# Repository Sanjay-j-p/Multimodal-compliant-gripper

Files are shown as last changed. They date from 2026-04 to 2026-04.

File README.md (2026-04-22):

# Multimodal Compliant Gripper with Force Feedback

> 🏆 **1st Place — Ford ATP Industrial Grasping Challenge** | Overall Honorable Mention  
> StarkHacks 2026 · Purdue University · 750+ Participants · Prize: Bambu Lab P2S



[]()

---

## Overview

A self-adaptive robotic grasper that combines **passive mechanical compliance**, **computer vision**, and **real-time Hall effect force feedback** to reliably grasp a wide variety of industrial objects without manual reconfiguration.

Built in 36 hours at StarkHacks 2026, tested on Ford automotive parts including spark plugs, lug nuts, piston rods, sheet metal, and more. Demonstrated on a Universal Robots UR10e cobot.

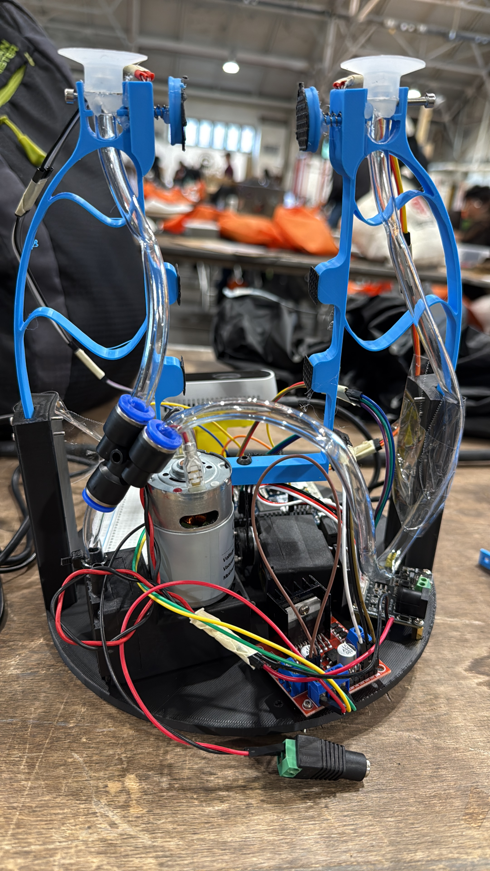
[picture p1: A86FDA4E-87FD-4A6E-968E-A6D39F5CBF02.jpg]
Gripper Hardware


---

## How It Works

### Grasp Decision Pipeline

```
RealSense D435i → SAM3 Segmentation → Depth Fusion → Grasp Classification → MQTT Command → Arduino Q → Actuator
```

1. **Capture** — Intel RealSense D435i streams aligned RGB + depth at 640×480 30fps
2. **Segment** — SAM3 via Roboflow API generates polygon masks for target objects
3. **Depth Fuse** — Mask projected onto depth matrix, point cloud extracted
4. **Classify** — Depth gap > 7 or std > 30 → `FINGER_GRASP`, else → `VACUUM`
5. **Execute** — MQTT command sent to Arduino Q, servo or pump actuated, Hall sensor monitors force

### Grasp Modes

| Mode | Trigger | Actuator |
|---|---|---|
| `FINGER_GRASP` | Hollow objects, irregular surfaces | SC Servo → compliant jaw |
| `VACUUM` | Large flat surfaces | DC pump → suction cups |

---

## System Architecture

### Three-Layer Control

```
[ Remote Client ]  ←→  MQTT  ←→  [ Linux Python Bridge ]  ←→  ArduinoBridge  ←→  [ Arduino Q ]
  mqtt_client.py                   mqtt_server_starkhacks.py                      mcu_starkhacks.ino
  - Send commands                  - Route MQTT to MCU                            - Servo control
  - Read force data                - Publish sensor data @ 20Hz                   - Pump PWM
                                   - Threading for async ops                      - Hall sensor read
```

### Force Feedback

Hall effect sensor reads displacement of a spring-loaded magnet in the fingertip. Displacement maps to contact force via:

```
F = -0.016 × M + 11.4   (calibrated linear regression, F in Newtons)
```

Where `M` is the raw analog Hall sensor reading. Published over MQTT at 20Hz for real-time monitoring.

---

## Hardware

| Component | Role |
|---|---|
| Compliant PLA fingers | Passive shape adaptation via flexure geometry |
| SC Servo (ID 1) | Jaw open/close, position range 1000–2200 |
| DC Vacuum Pump | Suction cup actuation, PWM controlled (0–255) |
| Suction Cups (×2) | Flat surface grasping |
| Hall Effect Sensor | Contact force estimation |
| Spring + Magnet | Displacement-to-force transduction |
| Arduino Q | MCU: all sensor reads + actuator control |
| Intel RealSense D435i | RGB-D perception, mounted on gripper |
| Linux laptop | MQTT broker + Python bridge server |
| UR10e | Robot arm (ISO 9409-1-50-4-M6 mount) |

More about the gripper: https://docs.google.com/document/d/11ORRFTWQD4MEVH4lIci75AOcohlwfsoFN2d4iKilZCc/edit?usp=sharing 

---

## Repository Structure

```
├── src/
│   ├── mcu_starkhacks.ino          # Arduino Q firmware
│   ├── mqtt_server_starkhacks.py   # Linux bridge server
│   ├── mqtt_client.py              # Remote command client
│   └── computer_vision.py          # Vision pipeline + grasp analysis
├── cad/
│   └── *.SLDPRT / *.STL            # SolidWorks CAD + print-ready files
└── README.md
```

---

## Software Setup

### Requirements

```bash
pip install paho-mqtt pyrealsense2 open3d opencv-python inference-sdk numpy
```

### Run

**1. Flash Arduino Q** with `src/mcu_starkhacks.ino`

**2. Start Linux bridge** (on robot laptop):
```bash
python src/mqtt_server_starkhacks.py
```

**3. Start vision pipeline** (point RealSense at scene, press `C` to capture):
```bash
python src/computer_vision.py
```

**4. Start remote client** (any machine on same network):
```bash
python src/mqtt_client.py
```

### Client Commands

| Key | Action |
|-----|---|
| `i` | Increase grip |
| `d` | Decrease grip |
| `r` | Release / reset |
| `p` | Pump ON |
| `o` | Pump OFF |
| `q` | Quit |

---

## Printing the Gripper

CAD files are in `/cad/`. Print settings:

- **Material**: PLA
- **Infill**: 20–30% for compliant fingers, 60%+ for structural mounts
- **Layer height**: 0.2mm
- **Supports**: Required for finger flexure zones
- **Printer**: Any FDM — tested on Bambu Lab P2S

---

## Team

| Name | Contribution |
|---|---|
| Sanjay Jayalakshmi Prabakar | Arduino Q MCU and Linux, Hall effect force feedback, vacuum/servo control |
| Sukesh J. Ranganathan | Mechanical design, CAD, 3D printing, assembly |
| Sai Siddartha Alleni | Vision pipeline, MQTT architecture |
| Yalamanchili Varshitha | Vision pipeline, Roboflow/SAM3 integration |

---

## Results

Tested on Ford automotive parts: spark plug, lug nut, piston rod, sheet metal, cabin air filter, door handle, wire harness, and more.

**[Watch full demo →](https://youtu.be/v_XWHwukWWc)**

---

## Built With

`Arduino Q` `Python` `MQTT` `SAM3` `Roboflow` `Intel RealSense` `PyRealSense2` `Open3D` `OpenCV` `SolidWorks` `SC Servo` `Universal Robots UR10e`

---

*StarkHacks 2026 · Humanoid Robotics Club · Purdue University · April 17–19, 2026*

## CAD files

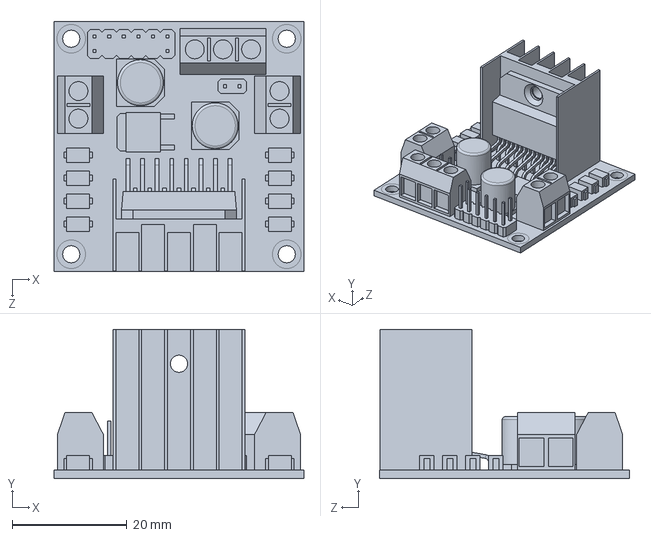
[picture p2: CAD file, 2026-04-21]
StarkHacks_CAD/L298N Motor Driver.SLDPRT
43.5 x 26.0 x 43.5 mm

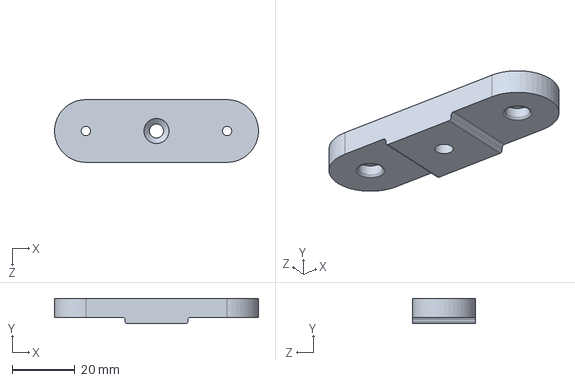
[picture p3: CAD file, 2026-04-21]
StarkHacks_CAD/Intel D435 mount.SLDPRT
65.0 x 8.00 x 20.0 mm

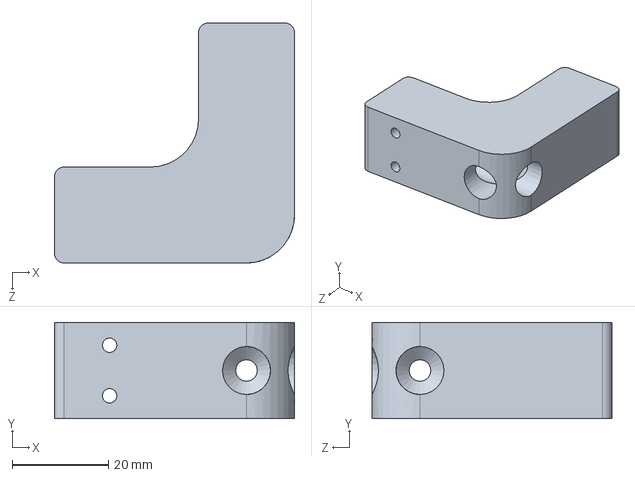
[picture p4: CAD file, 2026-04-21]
StarkHacks_CAD/Angle adapter 90 degree.SLDPRT
50.0 x 20.0 x 50.0 mm

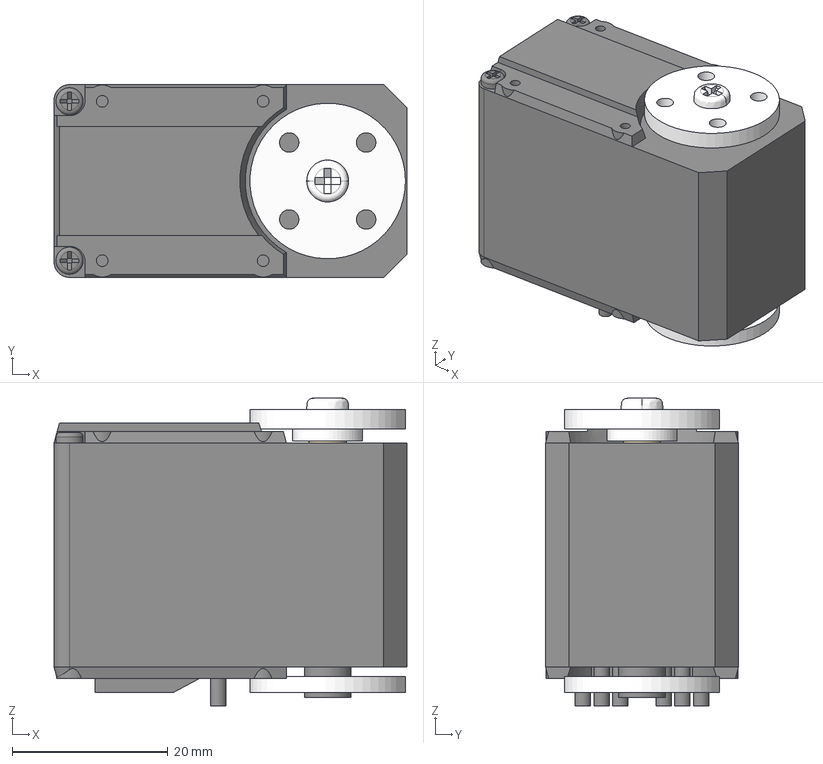
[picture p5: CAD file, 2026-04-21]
StarkHacks_CAD/STS3215_03a v1.step
45.4 x 24.8 x 39.6 mm
ac2
ac1
main

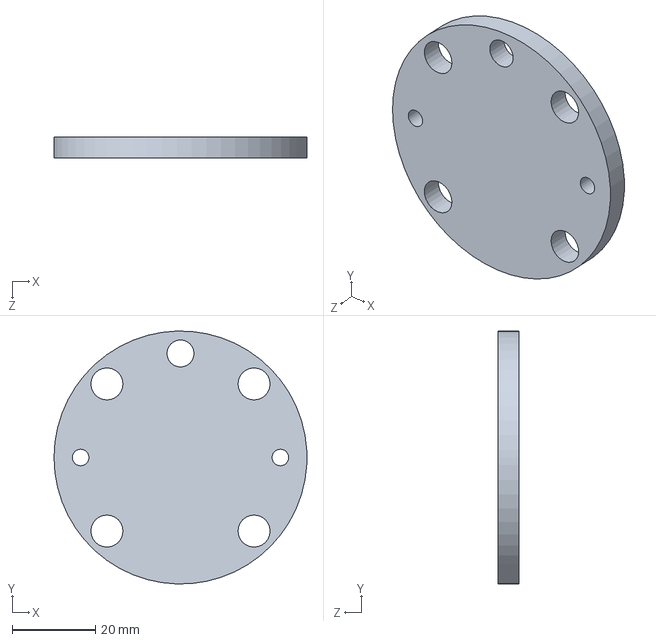
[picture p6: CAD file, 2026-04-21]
StarkHacks_CAD/Part for ur10e.SLDPRT
60.8 x 60.8 x 5.00 mm

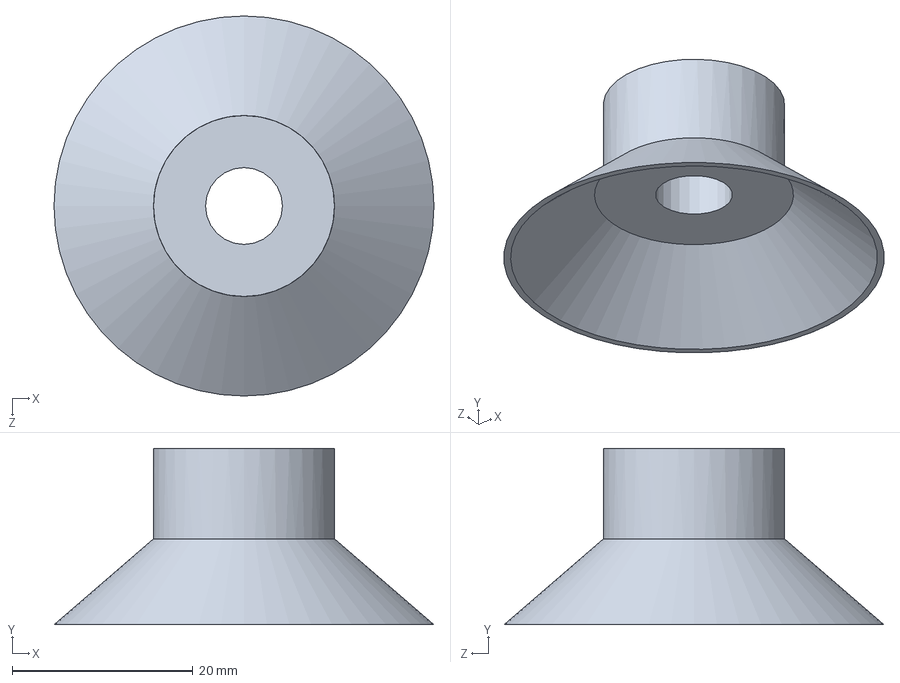
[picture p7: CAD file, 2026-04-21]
StarkHacks_CAD/VDF40XX.SLDPRT
42.0 x 19.5 x 42.0 mm

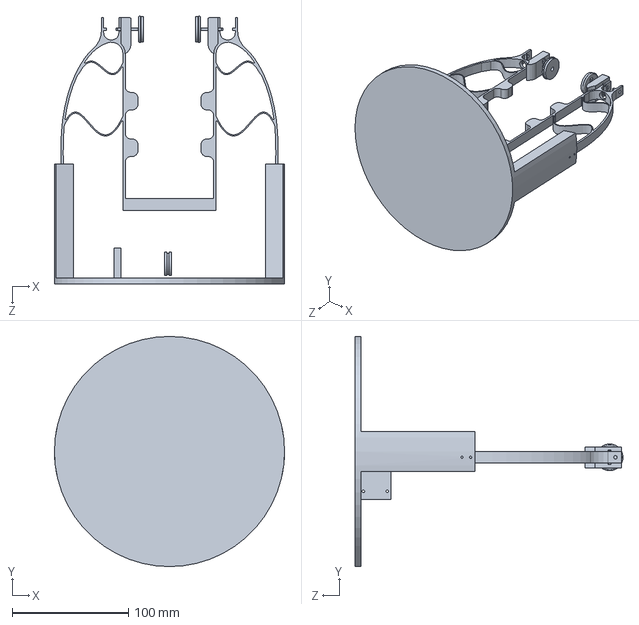
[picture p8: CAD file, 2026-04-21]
StarkHacks_CAD/Grasper Final.SLDPRT
197.7 x 197.7 x 230.1 mm

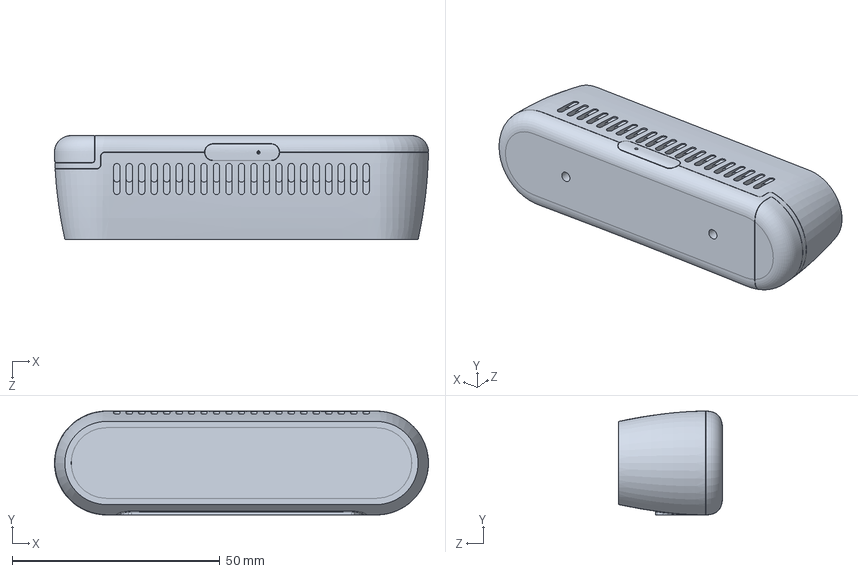
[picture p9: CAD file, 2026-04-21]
StarkHacks_CAD/IntelRealsense_D435_Multibody.SLDPRT
90.0 x 25.0 x 25.0 mm

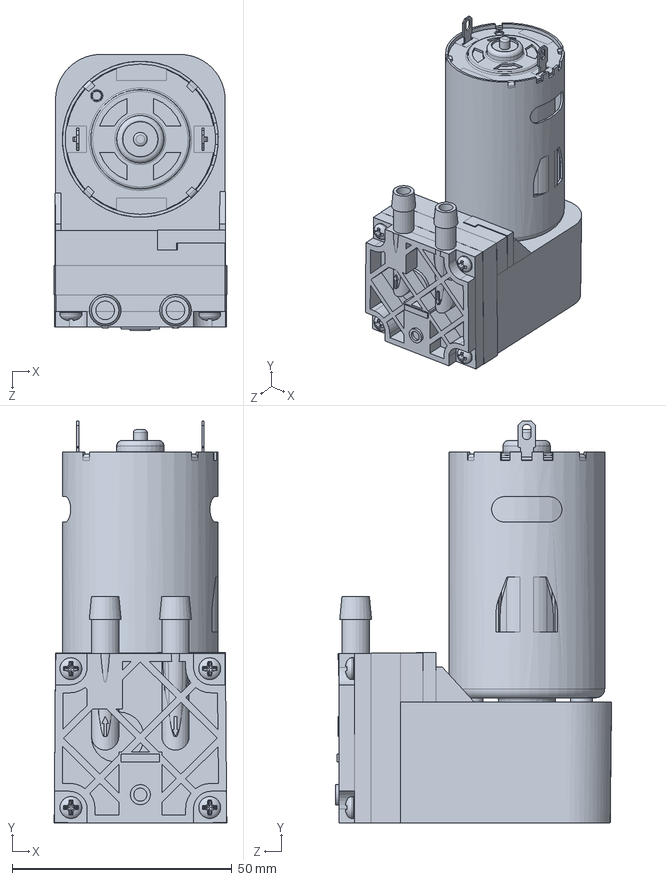
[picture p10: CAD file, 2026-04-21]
StarkHacks_CAD/D2028B-12V-Vacuum-Pump.SLDPRT
39.3 x 91.5 x 62.8 mm

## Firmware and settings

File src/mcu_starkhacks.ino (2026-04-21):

#include <SCServo.h>
#include "Arduino_RouterBridge.h"

const int hall_sensor = A0;
SMS_STS st;
const int enable_pin = 5;
const int in1 = 4;  
const int in2 = 3;  

void setup() {
    pinMode(enable_pin, OUTPUT);
    pinMode(in1, OUTPUT);
    pinMode(in2, OUTPUT);

    Serial.begin(1000000);
    st.pSerial = &Serial;
    delay(3000);

    Bridge.begin();
    Bridge.provide("grasp", pinch);
    Bridge.provide("suction", suction);  
    Bridge.provide("get_pos", get_pos);
    Bridge.provide("read_hall_value", read_hall_value);

    digitalWrite(in1, LOW);
    digitalWrite(in2, HIGH);
    delay(1000);
}

void loop() {}

float read_hall_value() {
    int M = analogRead(hall_sensor);  // raw hall value
    float F = -0.016 * M + 11.4;      // calibrated force (N)
    return F;
}

void pinch(int position) {
    st.WritePosEx(1, position, 1500, 50);
}

void suction(int voltage) {
    voltage = constrain(voltage, 0, 255);
    analogWrite(enable_pin, voltage);  
    delay(100);
}

int get_pos() {
    return st.ReadPos(1);
}

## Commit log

2026-04-21 Revise README for Multimodal Compliant Gripper
    Updated README to provide detailed information about the Multimodal Compliant Gripper project, including overview, system architecture, hardware components, software setup, and team contributions.
2026-04-22 Update README.md
    Added a description of gripper

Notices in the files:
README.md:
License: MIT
